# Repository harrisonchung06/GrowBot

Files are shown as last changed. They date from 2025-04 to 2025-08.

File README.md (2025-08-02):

# Cartesian Fruit-Picking Robot

### A Project by CPP Robotics Club  
**Goal:** Reduce agricultural waste by automating accurate and efficient produce picking.

---

## Project Overview

Every year, significant amounts of fruits go to waste due to inefficient produce picking. Our project addresses this issue by developing a **Cartesian robot** capable of autonomously identifying and picking ripe produce using:

- **Dual-camera** visual localization  
- A **Monte Carlo optimization algorithm** for target convergence  
- Fast and accurate **stepper motors**
- **Custom end effector** to pick each fruit accurately 

---

## Repository Contents

This repository includes everything needed to understand, replicate, and improve upon the project:

- `/code` — All source code, including the Monte Carlo control algorithm and camera processing scripts  
- `/cad` — Full CAD assemblies, individual part files, and previous iterations  
- `/bom` — Bill of Materials

---

## System Architecture

### 1. **Robot Design**
- **3-axis Cartesian system** for predictable linear motion  
- Custom end effector that cuts at the stem   
- **Modular** build using **low-cost materials**

### 2. **Vision System**
- Two RGB cameras provide **stereo** vision  
- **OpenCV** image processing to detect fruit centers

### 3. **Control Algorithm**
- Monte Carlo method used for iterative movement refinement  
- Robot converges on optimal gripper pose through probabilistic sampling  
- Tolerant to vision and motion errors

---

## Getting Started

### Prerequisites
- Python 3.9+  
- OpenCV  
- NumPy  
- 3D printer

### Build Instructions
- Find the Final Assembly file
- Cut all aluminium extrusions and belts to size defined in the assembly
- Attach supporting brackets and plates to the frame 
- Print all components found in the assembly that are not aluminium 
- Assemble motor carriage
  - Assemble the Z Axis 
  - Assemble the Y Axis
  - Attach the Z Axis to the Y Axis
  - Assemble the X Axis
  - Attach the YZ Axis assembly to the X Axis
  - Attach the XYZ Axis assembly to the frame
- Solder limit switches and attach to frame with adhesive
- Assemble and attach the claw
- Assemble and attach the Camera Mount 

### Code Setup Instructions

```bash
git clone https://github.com/harrisonchung06/GrowBot.git
cd code
pip install -r requirements.txt
python main.py
```

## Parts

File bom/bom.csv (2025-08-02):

Name/Description | Qty | Price | Unit Price
Aluminium Spacer | 20 | 9.99 | 0.4995
M5 40mm Machine Screw | 25 | 6.74 | 0.2696
M5 Lock Nuts | 35 | 5.23 | 0.1494285714
M3 40mm Screw | 15 | 2 | 0.1333333333
POM Wheels | 10 | 9.99 | 0.999
Logitech Webcam | 2 | 23.5 | 11.75
GT2 Pulley | 4 | 17.98 | 4.495
Carrier Drag Chain | 1 | 13.89 | 13.89
GT2 Timing Belt | 1 | 11.99 | 11.99
1220mm 2020 VSlot Aluminium Extrusions | 4 | 45.99 | 11.4975
Corner Plate | 12 | 19.99 | 1.665833333
1000mm 2020VSlot Aluminium Extrusions | 4 | 39.99 | 9.9975
TB6600 Stepper Motor Driver | 2 | 19.18 | 9.59
T Slide Nuts | 100 | 14.59 | 0.1459
23MM Nema 17 Stepper Motor | 3 | 19.18 | 6.393333333
40MM Nema 17 Stepper Motor | 1 | 12.99 | 12.99
USB Hub | 1 | 9.99 | 9.99
USB to Mini B Cable | 2 | 4.99 | 2.495
 | Total | 288.2

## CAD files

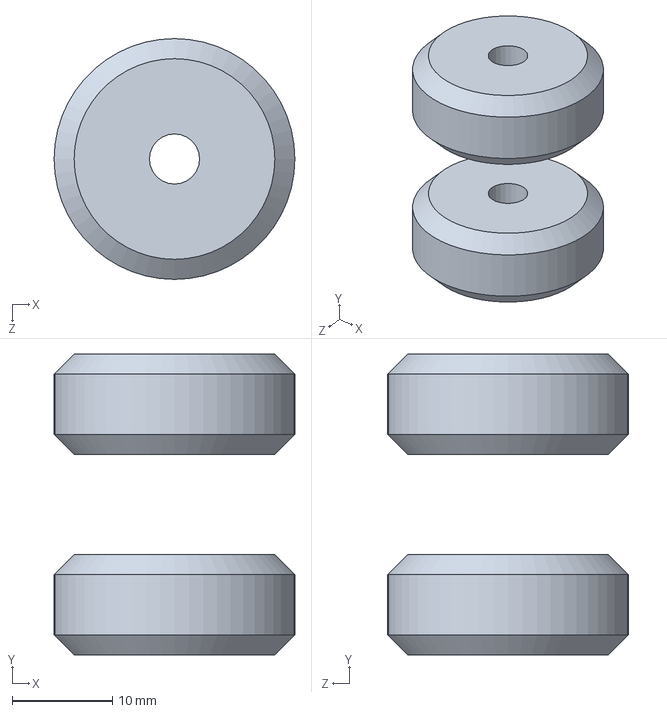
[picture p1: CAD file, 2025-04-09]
cad/Roller Test Assembly.SLDASM
24.0 x 30.0 x 24.0 mm
Roller x 2

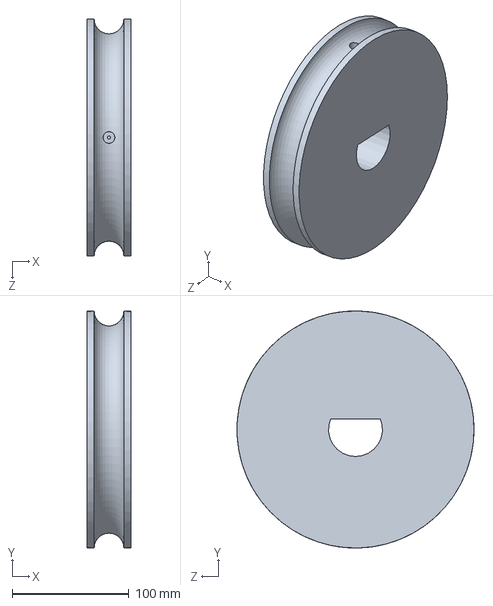
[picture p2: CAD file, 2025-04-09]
cad/Wheel.SLDPRT
38.1 x 203.2 x 203.2 mm

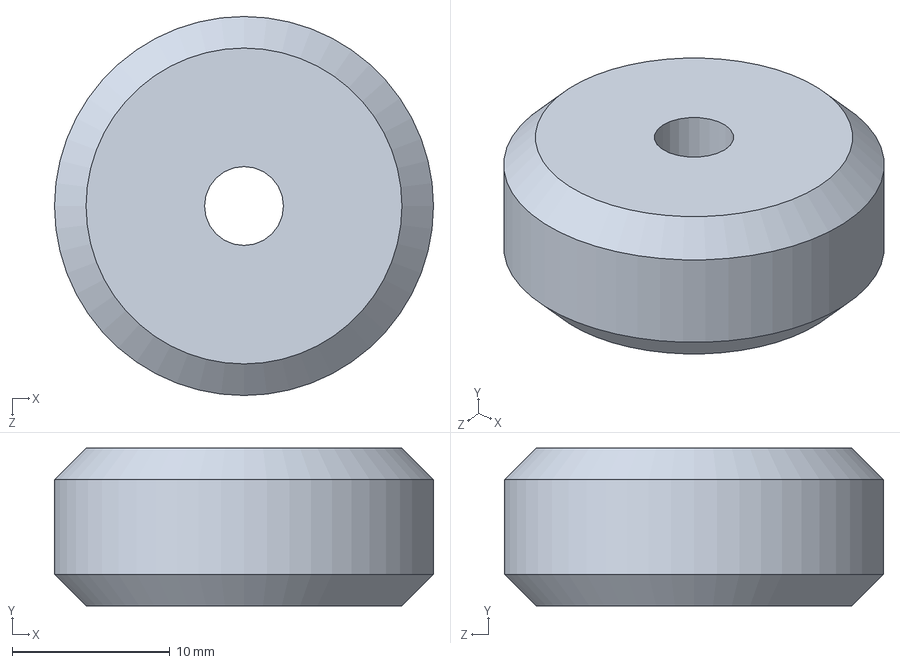
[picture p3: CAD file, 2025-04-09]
cad/Roller.SLDPRT
24.0 x 10.0 x 24.0 mm

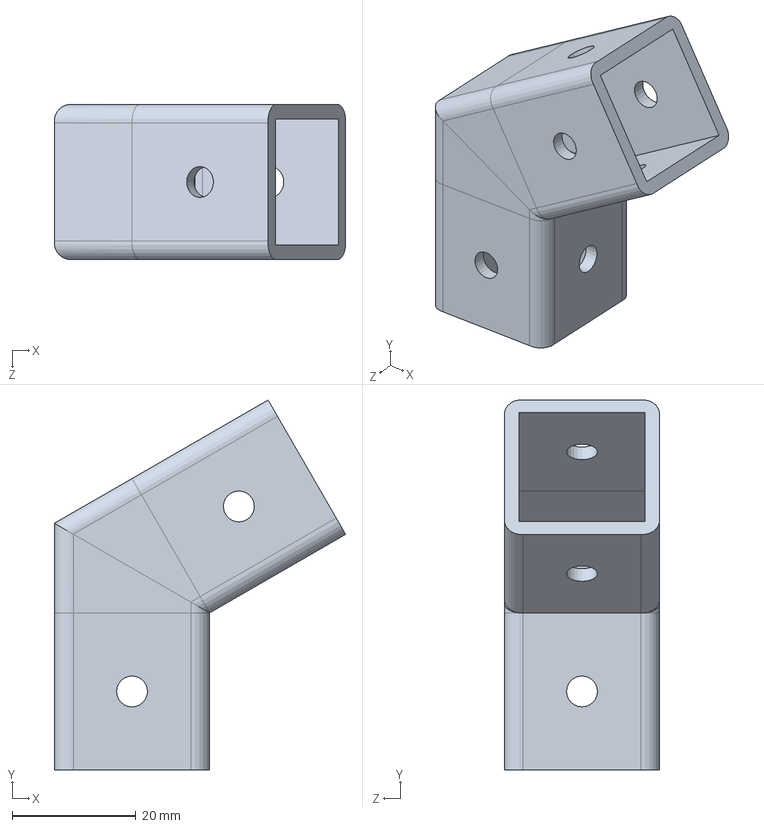
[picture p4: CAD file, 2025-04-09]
cad/2020Vslot Attachment 60 Degree.SLDPRT
47.1 x 59.8 x 25.1 mm

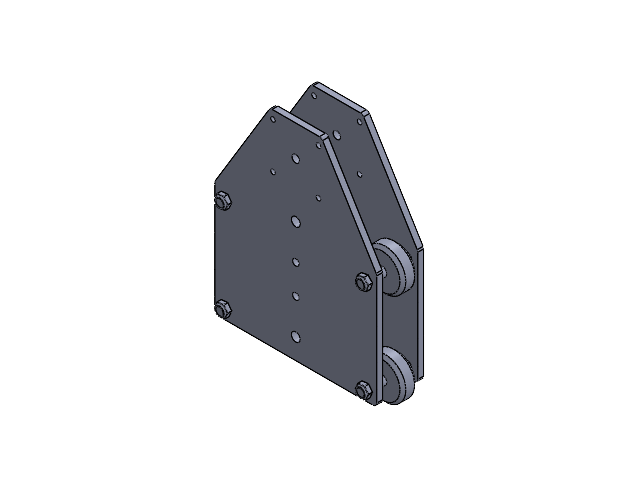
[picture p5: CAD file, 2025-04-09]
cad/RollerMechAssembly.SLDASM
RollerPlate x 2
Roller x 4
M5ScrewRoller x 4
M5ScrewRollerNut x 4
Spacer x 8

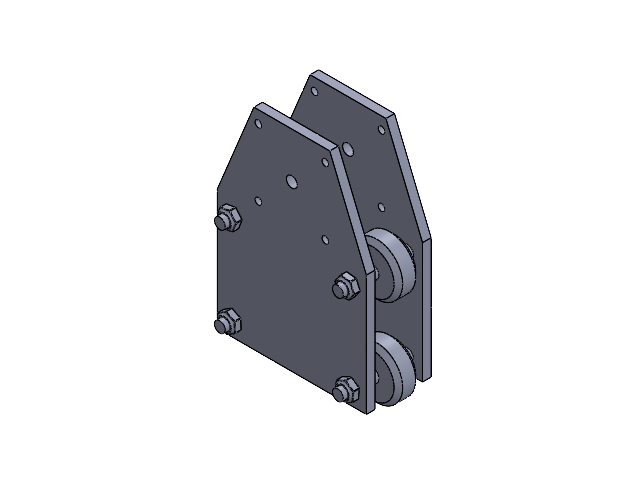
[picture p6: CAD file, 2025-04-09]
cad/ThirdAxisAssembly.SLDASM
ThirdAxisRollerPlate x 2
M5ScrewRollerNut x 4
M5ScrewRoller x 4
Spacer x 8
Roller x 4

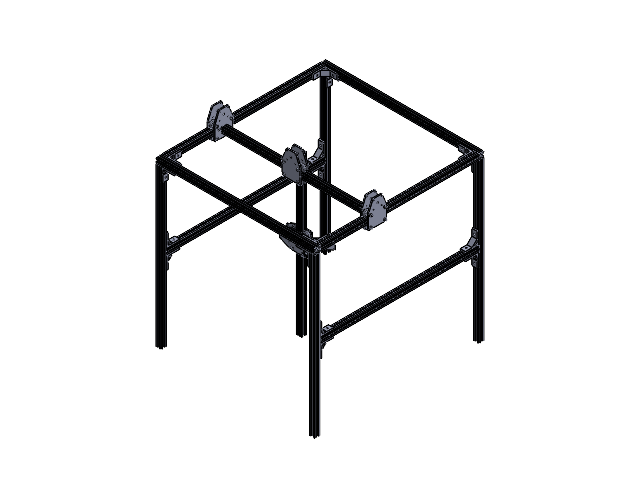
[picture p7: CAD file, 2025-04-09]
cad/FinalAssembly3.SLDASM
2020Vslot 24in x 11
ThirdAxisRollerPlate x 8
M5ScrewRollerNut x 16
M5ScrewRoller x 16
Spacer x 32
Roller x 16
2020Vslot 20in
2020Bracket x 16
CameraMount

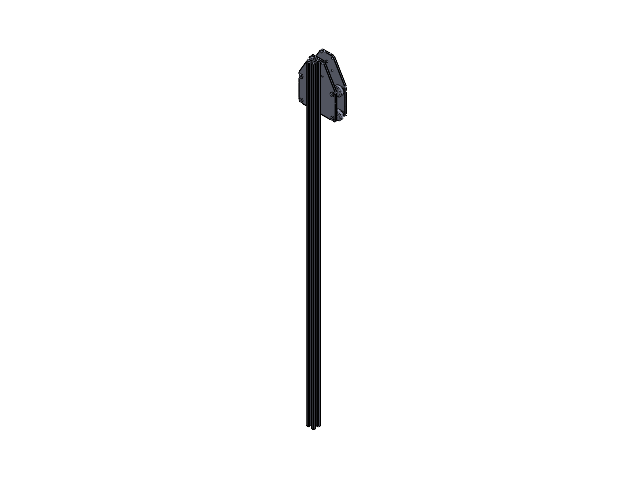
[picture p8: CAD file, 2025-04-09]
cad/SecondAxis.SLDASM
RollerPlate x 2
Roller x 4
M5ScrewRoller x 4
M5ScrewRollerNut x 4
Spacer x 8
SecondAxisVslot
M5Screw x 4

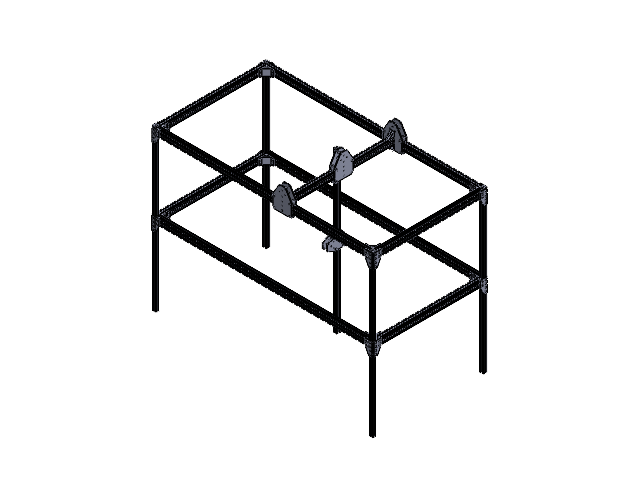
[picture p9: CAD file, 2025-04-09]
cad/FinalAssembly.SLDASM
2040Vslot 24in x 4
2040Vslot 48in x 4
2020Vslot 36in x 4
L6HolePlate x 16
M5Screw x 140
2040 Corner Bracket x 8
FirstAxis
RollerPlate x 6
Roller x 16
M5ScrewRoller x 16
M5ScrewRollerNut x 20
Spacer x 32
SmallBracket2 x 4
SecondAxisVslot
ThirdAxisRollerPlate x 2

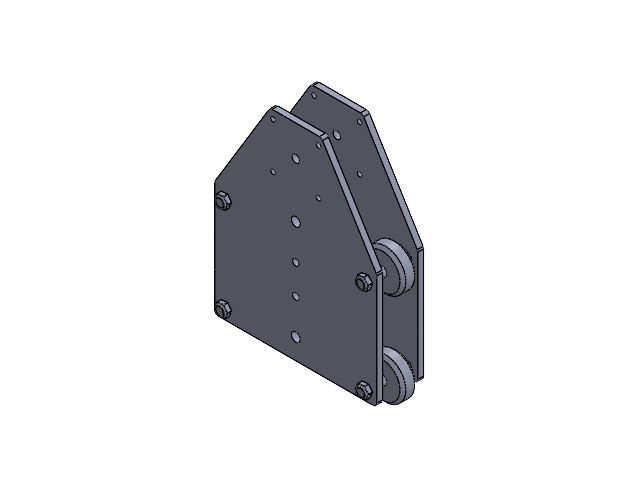
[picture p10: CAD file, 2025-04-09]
cad/SecondAxisRollerMechAssembly.SLDASM
RollerPlate x 2
Roller x 4
M5ScrewRoller x 4
M5ScrewRollerNut x 4
Spacer x 8

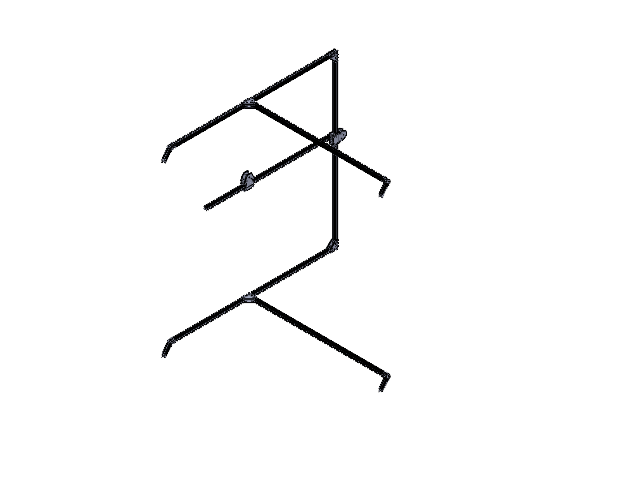
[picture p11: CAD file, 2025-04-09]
cad/FinalAssembly2.SLDASM
2020Vslot 48in x 3
2020Vslot 1000mm x 3
ThirdAxisRollerPlate x 4
M5ScrewRollerNut x 8
M5ScrewRoller x 8
Spacer x 16
Roller x 8
Small Bracket x 8
M5Screw x 72
2020Vslot Attachment x 2
2020Vslot Bit x 4
2020Vslot Attachment 60 Degree x 2

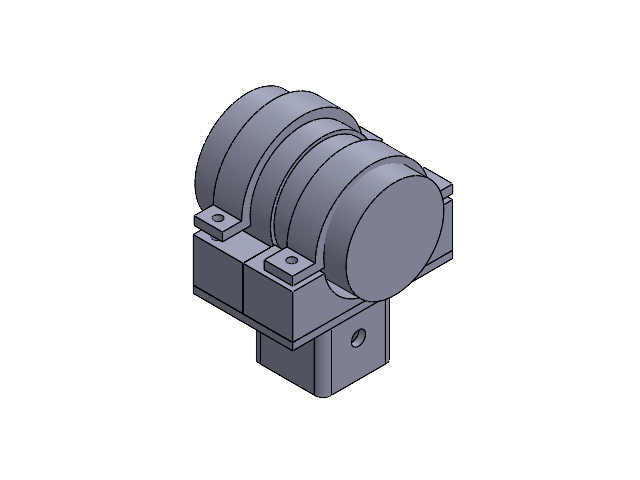
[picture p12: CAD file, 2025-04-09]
cad/MotorAttachmentAssembly.SLDASM
MotorAttachment
MotorBracket2
MotorBracket1
Motor

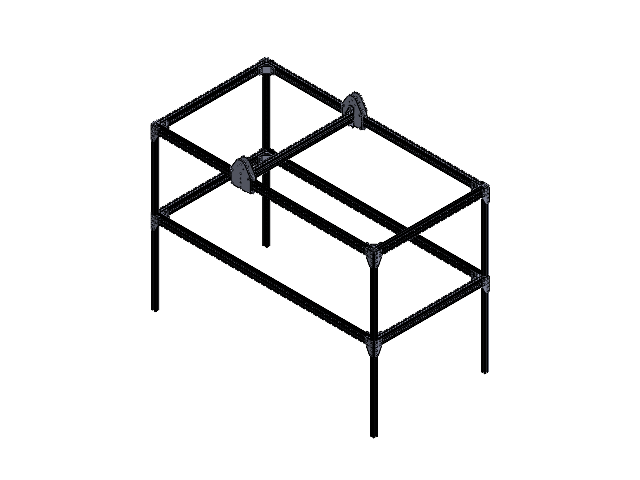
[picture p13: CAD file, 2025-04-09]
cad/FrameAssembly.SLDASM
2040Vslot 24in x 4
2040Vslot 48in x 4
2020Vslot 36in x 4
L6HolePlate x 16
M5Screw x 136
2040 Corner Bracket x 8
RollerPlate x 4
Roller x 8
M5ScrewRoller x 8
M5ScrewRollerNut x 12
Spacer x 16
FirstAxis
SmallBracket2 x 4

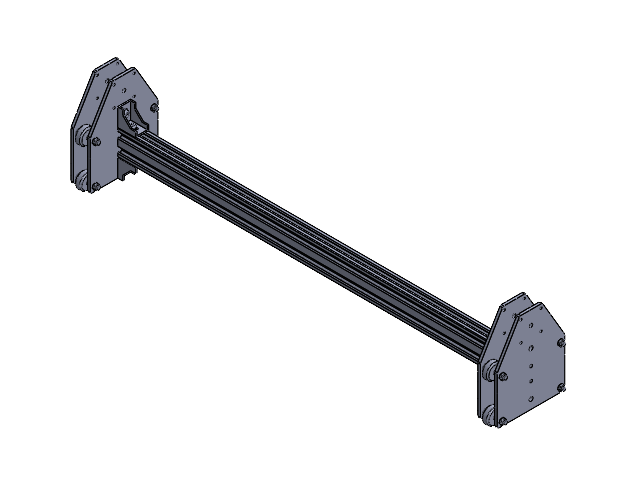
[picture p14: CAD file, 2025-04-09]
cad/FirstAxis.SLDASM
FirstAxis
RollerPlate x 4
Roller x 8
M5ScrewRoller x 8
M5ScrewRollerNut x 12
Spacer x 16
SmallBracket2 x 4
M5Screw x 8

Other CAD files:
cad/EndEffSecondAssem.SLDASM
cad/FrameAssem.SLDASM
cad/Robot3.SLDASM
cad/EndEff.SLDASM
cad/2020Bracket.SLDPRT
cad/2020Vslot 1000mm.SLDPRT
cad/2020Vslot 20in.SLDPRT
cad/2020Vslot 24in.SLDPRT
cad/2020Vslot 36in.SLDPRT
cad/2020Vslot 48in.SLDPRT
cad/2020Vslot Attachment.SLDPRT
cad/2020Vslot Bit.SLDPRT
cad/2020Vslot Template.SLDPRT
cad/2040 Corner Bracket.SLDPRT
cad/2040Vslot 1220mm.SLDPRT
cad/2040Vslot 24in.SLDPRT
cad/2040Vslot 48in.SLDPRT
cad/2040Vslot Template.SLDPRT
cad/CameraCover.SLDPRT
cad/CameraMount.SLDPRT
cad/EndEff1.SLDPRT
cad/EndEffBase.SLDPRT
cad/EndEffSecond1.SLDPRT
cad/EndEffSecond2.SLDPRT
cad/FirstAxis.SLDPRT
cad/L6HolePlate.SLDPRT
cad/M5Screw.SLDPRT
cad/M5ScrewRoller.SLDPRT
cad/M5ScrewRollerNut.SLDPRT
cad/Mild Steel Sq Tube 24in.SLDPRT
cad/Motor.SLDPRT
cad/MotorAttachment.SLDPRT
cad/MotorBracket1.SLDPRT
cad/MotorBracket2.SLDPRT
cad/Nut.SLDPRT
cad/Part5.SLDPRT
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

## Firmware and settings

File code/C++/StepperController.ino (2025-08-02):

#include <AccelStepper.h>
#include <Servo.h>

#define MOTOR_INTERFACE_TYPE AccelStepper::DRIVER

#define DIR_PIN_X 8
#define PUL_PIN_X 7

#define DIR_PIN_Y 12
#define PUL_PIN_Y 11

#define DIR_PIN_Z 10
#define PUL_PIN_Z 9

#define SWITCH_PIN_R_X 6
#define SWITCH_PIN_L_X 5

#define SWITCH_PIN_R_Y 3
#define SWITCH_PIN_L_Y 4

#define SWITCH_PIN_R_Z 14
#define SWITCH_PIN_L_Z 2

const int MAX_SPEED = 1000;
const int ACCELERATION = 1000; 

AccelStepper x(MOTOR_INTERFACE_TYPE, PUL_PIN_X, DIR_PIN_X);
AccelStepper y(MOTOR_INTERFACE_TYPE, PUL_PIN_Y, DIR_PIN_Y);
AccelStepper z(MOTOR_INTERFACE_TYPE, PUL_PIN_Z, DIR_PIN_Z);

Servo claw;

int MAX_X_STEPS = 0;  
int MAX_Y_STEPS = 0;  
int MAX_Z_STEPS = 0;  
int max_positions[3];

int x_pos;
int y_pos;
int z_pos;

int claw_pos;

String str;

void setup() {
  pinMode(SWITCH_PIN_R_X, INPUT_PULLUP);
  pinMode(SWITCH_PIN_L_X, INPUT_PULLUP);
  pinMode(SWITCH_PIN_R_Y, INPUT_PULLUP);
  pinMode(SWITCH_PIN_L_Y, INPUT_PULLUP);
  pinMode(SWITCH_PIN_R_Z, INPUT_PULLUP);
  pinMode(SWITCH_PIN_L_Z, INPUT_PULLUP);
  
  x.setMaxSpeed(MAX_SPEED);
  x.setAcceleration(ACCELERATION);
  x.setSpeed(MAX_SPEED);   

  y.setMaxSpeed(MAX_SPEED);
  y.setAcceleration(ACCELERATION);
  y.setSpeed(MAX_SPEED);

  z.setMaxSpeed(MAX_SPEED);
  z.setAcceleration(ACCELERATION);
  z.setSpeed(MAX_SPEED);

  claw.attach(13);

  Serial.begin(9600);

  while(1) {
    if (Serial.available() > 0) {
      String command = Serial.readStringUntil('\n');
      if (command == "HOME") { 
        home();
        break;
      }
    }
  }
}

int home() {
  MAX_X_STEPS = 0;
  MAX_Y_STEPS = 0;
  MAX_Z_STEPS = 0;

  int right_switchState_x = digitalRead(SWITCH_PIN_R_X);
  int left_switchState_x = digitalRead(SWITCH_PIN_L_X);

  int right_switchState_y = digitalRead(SWITCH_PIN_R_Y);
  int left_switchState_y = digitalRead(SWITCH_PIN_L_Y);

  int right_switchState_z = digitalRead(SWITCH_PIN_R_Z);
  int left_switchState_z = digitalRead(SWITCH_PIN_L_Z);

  claw_pos = 80;
  claw.write(claw_pos);
  
  
  while (right_switchState_x == LOW) { 
    right_switchState_x = digitalRead(SWITCH_PIN_R_X);
    x.runSpeed();
  }
  
  x.stop();  
  x.setCurrentPosition(0);  
  x.setSpeed(-MAX_SPEED);

  while (left_switchState_x == LOW) {
    left_switchState_x = digitalRead(SWITCH_PIN_L_X);
    x.runSpeed();
  }
  x.stop();

  while (right_switchState_y == LOW) { 
    right_switchState_y = digitalRead(SWITCH_PIN_R_Y);
    y.runSpeed();
  }
  y.stop();  
  y.setCurrentPosition(0);  
  y.setSpeed(-MAX_SPEED);

  while (left_switchState_y == LOW) {
    left_switchState_y = digitalRead(SWITCH_PIN_L_Y);
    y.runSpeed();
  }
  y.stop();

  while (right_switchState_z == LOW) { 
    right_switchState_z = digitalRead(SWITCH_PIN_R_Z);
    z.runSpeed();
  }
  z.stop();  
  z.setCurrentPosition(0);  
  z.setSpeed(-MAX_SPEED);

  while (left_switchState_z == LOW) {
    left_switchState_z = digitalRead(SWITCH_PIN_L_Z);
    z.runSpeed();
  }
  z.stop();
  
  MAX_X_STEPS = x.currentPosition();
  MAX_Y_STEPS = y.currentPosition();
  MAX_Z_STEPS = z.currentPosition();

  x.setCurrentPosition(0);
  y.setCurrentPosition(0);
  z.setCurrentPosition(0);

  max_positions[0] = abs(MAX_X_STEPS);
  max_positions[1] = abs(MAX_Y_STEPS);
  max_positions[2] = abs(MAX_Z_STEPS);

  Serial.print("MAX:");
  for (int i =0; i<3;i++){
    Serial.print(max_positions[i]);
    if (i<2){
      Serial.print(",");
    }
  }
  Serial.println();
}

void loop() {
  if (Serial.available()) {
    String input = Serial.readStringUntil('\n');
    input.trim();
    if (input == "PING"){
      Serial.println("POS:" + String(x.currentPosition()) + "," + String(y.currentPosition()) + "," + String(z.currentPosition()));
    } else if (input.startsWith("CLW:")) {
      int target = input.substring(4).toInt();
      if (target > claw_pos){
        for (int i = claw_pos; i<=target; i++){
          claw.write(i);
          delay(10); 
        }
      } else{
        for (int i = claw_pos; i>=target; i--){
          claw.write(i);
          delay(10); 
        }
      }
      claw_pos = target;
      Serial.println("CLAW_DONE");
    } else {
      String old_input = input;
      input = input.substring(4);  

      int values[6];
      for (int i = 0; i < 6; i++) {
        int commaIndex = input.indexOf(',');
        if (commaIndex != -1 && i < 5) {
          values[i] = input.substring(0, commaIndex).toInt();
          input = input.substring(commaIndex + 1);
        } else {
          values[i] = input.toInt();  
        }
      }

      int dx = 0;
      int dy = 0;
      int dz = 0;
      int vx = 0;
      int vy = 0;
      int vz = 0;
      long target_x = 0;
      long target_y = 0;
      long target_z = 0;
      bool in_bounds = true;

      if (old_input.startsWith("STP:")){
        dx = values[0];
        dy = values[1];
        dz = values[2];
        vx = values[3];
        vy = values[4];
        vz = values[5];

        target_x = x.currentPosition() + dx;
        target_y = y.currentPosition() + dy;
        target_z = z.currentPosition() + dz;

      } else if (old_input.startsWith("POS:")){
        target_x = values[0];
        target_y = values[1];
        target_z = values[2];

        dx = target_x - x.currentPosition();
        dy = target_y - y.currentPosition();
        dz = target_z - z.currentPosition();
        vx = values[3];
        vy = values[4];
        vz = values[5];
      }
      
      if (target_x < 0 || target_x > max_positions[0]) in_bounds = false;
      if (target_y < 0 || target_y > max_positions[1]) in_bounds = false;
      if (target_z < 0 || target_z > max_positions[2]) in_bounds = false;

      if (in_bounds) {
        if (dx != 0) {
          x.setMaxSpeed(abs(vx));
          x.move(dx);
        }
        if (dy != 0) {
          y.setMaxSpeed(abs(vy));
          y.move(dy);
        }
        if (dz != 0) {
          z.setMaxSpeed(abs(vz));
          z.move(dz);
        }

        x.runToPosition();
        y.runToPosition();
        z.runToPosition();

        Serial.println("DONE");
      } else {
        Serial.println("ERR:OUT_OF_BOUNDS");
      }
    } 
  }
}

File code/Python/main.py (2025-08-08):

from cam_thread import CameraThread
from motor_controller import MotorController
from pyusbcameraindex import enumerate_usb_video_devices_windows
import random
import time
import numpy as np
import math 

def get_latest_frame(queue):
    latest = None
    while not queue.empty():
        latest = queue.get()
    return latest

def get_score(threads, camera_indices):
    infos = []
    squared_dists = [0] * len(camera_indices)
    side_squared_dists = [0] * len(camera_indices)
    #Get info 
    for thread in threads:
        latest_info = get_latest_frame(thread.queue)
        if latest_info is not None:
            #print(f'Index: {thread.camera_index} Queue: {thread.queue.get()}')
            infos.append(latest_info)
            time.sleep(0.02)
    #Find the largest object 
    if infos:
        largest_areas = []
        largest_indices = []
        #Find the largest areas inside the info list and place the area inside the largest areas list and the indices to find the largest areas 
        for i in range(len(infos)):
            largest_area = 0
            largest_index = -1
            if infos[i][1]:
                for j in range(len(infos[i][1])):
                    if infos[i][1][j] > largest_area:
                        largest_area = infos[i][1][j]
                        largest_index = j
                largest_areas.append(largest_area)
                largest_indices.append(largest_index)
            else:
                largest_areas.append(largest_area)
                largest_indices.append(largest_index)

        for i in range(len(largest_indices)):
            #print(f'largest areas: {largest_areas}, largest indices: {largest_indices}, all info: {infos}')
            camera_center = infos[i][2]
            cam_y = camera_center[0]
            cam_z = camera_center[1]
            
            if i == 0: #Left cam min right 
                camera_side_y = 0
            elif i ==1: #Rigth cam min left 
                camera_side_y = 2*cam_y
            
            try:
                largest_center = infos[i][0][largest_indices[i]]
                
                if largest_indices[i] == -1:
                    largest_center = (float('inf'), float('inf'))
            except IndexError:
                largest_center = (float('inf'), float('inf'))

            large_y = largest_center[0]
            large_z = largest_center[1]

            #print(f'Cam_y {cam_y}, large_y {large_y}, cam_z {cam_z}, large_z {large_z}')
            #print(f' SIDE Cam_y {camera_side_y}, large_y {large_y}, cam_z {cam_z}, large_z {large_z}')
            squared_dist = (cam_y - large_y)**2 + (cam_z - large_z)**2
            squared_dists[i] = squared_dist

            side_squared_dist = (camera_side_y - large_y)**2 + (cam_z - large_z)**2
            side_squared_dists[i] = side_squared_dist
        

        valid_dists = []
        for i in range(len(squared_dists)):
            if not math.isinf(squared_dists[i]) and not squared_dists[i] == 0:
                valid_dists.append(squared_dists[i])
        valid_side_dists = []
        for i in range(len(side_squared_dists)):
            if not math.isinf(side_squared_dists[i]) and not side_squared_dists[i] == 0:
                valid_side_dists.append(side_squared_dists[i])
        
        print(f'valid distances {valid_dists}')
        print(f'valid side dists {valid_side_dists}')

        if len(valid_dists) == 2:
            print(f'both cams ')
            return sum(valid_dists)/len(valid_dists)
        elif len(valid_dists) == 1:
            print(f'one cam {valid_side_dists[0] * 1e3}')
            return valid_side_dists[0] * 1e3
        else:
            print(f'no cam')
            return float('inf')
    else:
        return float('inf')

def main():
    # Camera setup
    camera_indices = [0,1]  
    threads = []
    for index in camera_indices:
        thread = CameraThread(index)
        thread.start()
        threads.append(thread)

    # Motor setup
    arduino_port = 'COM4' 
    baud_rate = 9600
    controller = MotorController(arduino_port, baud_rate)
    controller.home()
    
    # Start at center position
    center_pos = [int(controller.max[0]//2), 
                 int(controller.max[1]//2), 
                 int(controller.max[2]//2)]
    controller.move_to_position(*center_pos, 5000, 5000, 5000)
    current_pos = center_pos.copy()

    # Monte Carlo parameters
    stop_score = 15000 #~50 mm away from the fruit stem 
    step_per_mm = 50.93
    max_iterations = 40
    temp = 1000  # Initial temperature
    cooling_rate = 0.97
    step_size = 5000  # Initial step size
    min_step = 100
    best_score = float('inf')
    best_pos = current_pos.copy()

    while True:
        temp=1000
        step_size = step_size + 1000
        for iteration in range(max_iterations):
            
            current_score = get_score(threads, camera_indices)
            print(f"curr score {current_score}")
            # Generate random neighbor (within bounds)
            while True:
                neighbor_pos = [
                    current_pos[0] + random.randint(-step_size, step_size),
                    current_pos[1] + random.randint(-step_size, step_size),
                    current_pos[2] + random.randint(-int(step_size*0.5), int(step_size*0.5))
                ]
                
                # Ensure within bounds
                if all(0 <= p <= m for p, m in zip(neighbor_pos, controller.max)):
                    break

            # Move to neighbor position
            controller.move_to_position(*neighbor_pos, 5000, 5000, 5000)
            print(f"neighbor {neighbor_pos}")

            new_score = get_score(threads, camera_indices)

            print(f"new score{new_score}")

            # Acceptance probability (simulated annealing)
            delta = new_score - current_score
            accept_prob = np.exp(-delta / temp) if temp > 0 else 0
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

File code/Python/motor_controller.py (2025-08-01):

import serial
import time

class OutOfBoundsError(Exception):
    def __init__(self, message="Movement exceeds machine bounds"):
        super().__init__(message)

class MotorController():
    def __init__(self, port, baud_rate):
        self.baud_rate = baud_rate
        self.port = port 
        self.arduino = serial.Serial(port, baud_rate, timeout=1)
        self.max = None
        time.sleep(2)

    def home(self):
        print("Sending home command")
        self.arduino.write(b'HOME\n') 
        print("Command sent")
        while True:
            if self.arduino.in_waiting > 0:
                data = self.arduino.readline().decode('utf-8').strip()
                if data.startswith("MAX:"):
                    max = data[4:]
                    max=[abs(int(num)) for num in max.split(",")]
                    self.max = max
                    print(f"Home command completed {max}")
                    return self.max
                
    def move_to_position(self, x,y,z,vx=1000,vy=1000,vz=1000):
        command = f"POS:{x},{y},{z},{vx},{vy},{vz}\n"
        print(command)
        self.arduino.write(command.encode())
        while True:
            if self.arduino.in_waiting:
                response = self.arduino.readline().decode().strip()
                if response == "DONE":
                    print(f"moved to position {x},{y},{z}")
                    break
                elif response == "ERR:OUT_OF_BOUNDS":
                    raise OutOfBoundsError(f"Movement would exceed machine bounds.")

    def move_step(self, dx,dy,dz, vx=1000,vy=1000,vz=1000):
        command = f"STP:{dx},{dy},{dz},{vx},{vy},{vz}\n"
        self.arduino.write(command.encode())
        print("command sent")
        while True:
            if self.arduino.in_waiting:
                response = self.arduino.readline().decode().strip()
                if response == "DONE":
                    print(f"moved {dx} {dy} {dz} with speed {vx}, {vy}, {vz}")
                    break
                elif response == "ERR:OUT_OF_BOUNDS":
                    raise OutOfBoundsError(f"Movement would exceed machine bounds.")

    def move_claw(self, angle):
        if not (0 <= angle <= 80):
            raise ValueError("Claw angle must be between 0 and 180")
        
        command = f"CLW:{angle}\n"
        self.arduino.write(command.encode())
        print(f"Sent claw command: {command.strip()}")
        
        while True:
            if self.arduino.in_waiting:
                response = self.arduino.readline().decode().strip()
                if response == "CLAW_DONE":
                    print("Claw move complete")
                    break
    
    def ping_position(self):
        command = f"PING\n"
        self.arduino.write(command.encode())
        while True:
            if self.arduino.in_waiting:
                response = self.arduino.readline().decode().strip()
                if response.startswith("POS:"):
                    pos = response[4:]
                    pos = [int(n) for n in pos.split(",")]
                    print(f"Current Position: {pos}")
                    return pos

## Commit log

2025-03-24 Added fruit detection program
    - Uses cv2 and numpy to get webcam feed, mask out red pixels, and detect contours
    Still need to:
    - add contour filtering--get rid of contours that are below a certain size/tell us no useful information
    - refine color ranges for detection as well as threshold value filter to optimize detection of certain fruits/berries
2025-03-30 Update cv2_fruit_detection.py
    - Refined color ranges using a strawberry
    - Renamed draw_contour_centers to contour_centers, and made it return a list of the center points of each contour
    - Added "filter_contours" function to remove contours below a certain size from the list of given contours, then return the filtered list
    - moved blob detection code into "detect_blobs" function that returns contours
2025-08-01 Full working code
    [2020Bracket.SLDPRT, 2020Vslot 1000mm.SLDPRT, 2020Vslot 20in.SLDPRT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]
2025-08-02 add extra files
    [2020Bracket.SLDPRT, 2020Vslot 1000mm.SLDPRT, 2020Vslot 20in.SLDPRT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]
2025-08-08 bias the optimization function + fix usb problem+reset step for more exploration
    [main.py]
